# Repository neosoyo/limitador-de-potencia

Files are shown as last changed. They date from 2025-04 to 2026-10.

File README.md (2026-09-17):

# Limitador de Potência
Dispositivo para medição de potência e consumo com controlador de limitador de potência para propulsão elétrica de Aeronaves rádio controladas.

# Configurador

Aplicativo para visualização de daods e ajustes da malha de controle.

# Hardware
Utiliza MCU nrf52 (xiao ble), com os seguintes periféricos:

| Periférico | Descrição |
|---|---|
| INA226 | Leitor de corrente, tensão e potência, R shunt de 50mOhms |
| SK6812mini | Led rgba para indicão de status |
| Saída PWM | com BSS138 para ajuste de nível lógico em 5Vdc |
| Entrada PWM | com BSS138 para ajuste de nível lógico para 3.3Vdc |
| Saída UART | 115200 bps, saída de dados em tempo real do control | 
| BLE | Transmissão de informações me tempo real via BLE |

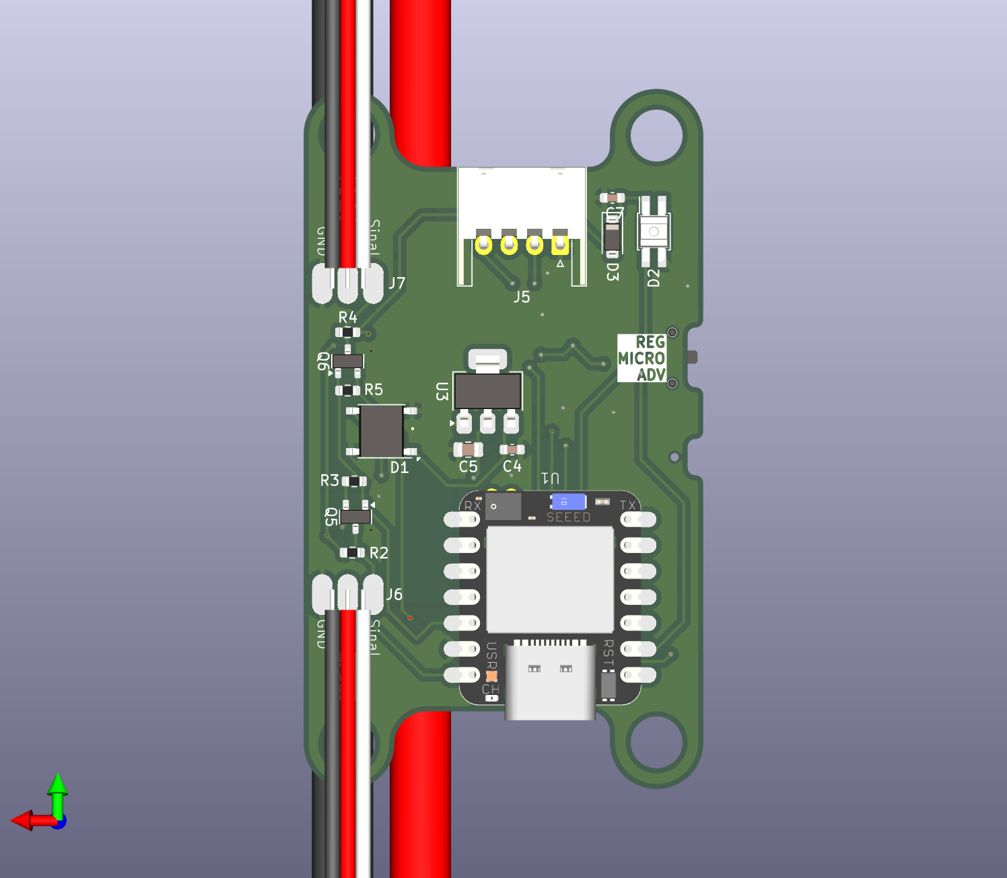
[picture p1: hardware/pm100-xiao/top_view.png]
PM100 Top rev2

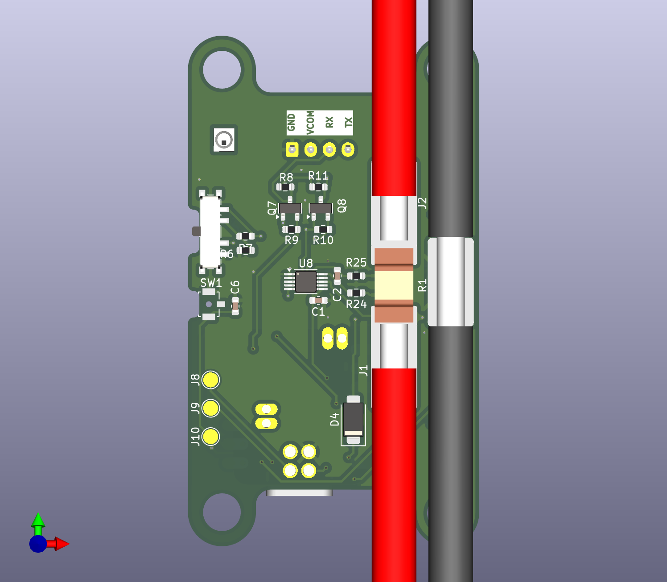
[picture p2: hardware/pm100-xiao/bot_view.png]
PM100 bot rev2


# Firmware

Metas:

* Executar limitação de potência regulando sinal PWM utilizando mensurações do INA226 e uma malha de controle to tipo ADRC.
* Fornecer Potência, Tensão, Corrente, Energia Consumida e sinais PWMs (entrada, controle e saída) pela porta UART.
* Permitir a configuração de número de idenficação e ajuste da malha de controle pela porta USB.
* Através de comunicação bluetooth BLE, transmitir tempo total ligado em segundos, potência máxima, número de identificação e acumulado de energia consumida.
* Suportar bootloader com assinatura de firmware.

# Futuro

Adicionar um monitor de células da bateria: https://www.analog.com/media/en/technical-documentation/data-sheets/ltc6810-1-6810-2.pdf

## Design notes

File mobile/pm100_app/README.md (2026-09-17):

# PM100 Power Limiter — Flutter BLE App

A Flutter + Dart mobile app that connects to the **PM100 Power Limiter** over
Bluetooth Low Energy (BLE), displays live telemetry, and sends a "blink" command
to the device.

- **Stack:** Flutter (Dart), `flutter_blue_plus`
- **Platforms:** Android, iOS
- **Device:** PM100 Power Limiter (Seeed Studio Xiao BLE, Zephyr-based firmware)

---

## Features

- Scan for nearby BLE devices and connect to the PM100.
- Secure pairing via MITM passkey (the device requires encryption on all GATT
  characteristics; the OS shows the numeric PIN prompt automatically).
- Subscribe to `NOTIFY` characteristics for live telemetry updates.
- Read `READ`-only characteristics (Uptime, Team Name, Team Number) on connect
  and via a manual refresh button.
- Send the **White Blink** command (`0x01`) from a dedicated button.
- Decode and scale the raw binary payloads into human-readable values.
- Show **PWM Signals** as three 0–2000 µs progress bars.
- Light / dark theme toggle (initialized from the phone's brightness), using Android's **Material You** dynamic color (via `dynamic_color`), falling back to a seed color elsewhere.

---

## Project structure

```
lib/
  main.dart                          # App entry, theme, HomeScreen (view switch)
  models/
    pm100_spec.dart                  # UUIDs, variable definitions, value decoders
  services/
    pm100_ble_controller.dart        # BLE lifecycle + state (ChangeNotifier)
  screens/
    scan_screen.dart                 # Device discovery & connection UI
    device_screen.dart               # Telemetry list + Blink button

test/
  widget_test.dart                   # Unit tests for value formatting

android/app/src/main/AndroidManifest.xml  # BLE permissions
ios/Runner/Info.plist                      # Bluetooth usage descriptions
```

### Architecture

- `Pm100BleController` is a `ChangeNotifier` that owns the entire BLE
  lifecycle. The UI is stateless and rebuilds through a `ListenableBuilder`.
- `HomeScreen` switches between `ScanScreen` and `DeviceScreen` based on
  `controller.isReady`.

```mermaid
flowchart TD
    A[ScanScreen] -->|tap device| B[connect]
    B --> C[discoverServices]
    C --> D[Subscribe NOTIFY characteristics]
    D --> E[Read READ characteristics]
    E --> F[DeviceScreen - live telemetry]
    F --> G[Blink button writes 0x01]
    F --> H[Refresh re-reads values]
    H --> F
    F -->|disconnect| A
```

---

## BLE service specification

### Service UUID

| Item | UUID |
|---|---|
| **PM100 Service** | `E20A1A00-473B-4444-9F6D-BE083A8BD92D` |

Standard 16-bit SIG characteristics use the Bluetooth Base UUID
`0000XXXX-0000-1000-8000-00805F9B34FB`. Custom characteristics use their full
128-bit UUID.

### Characteristics

| Parameter | GATT name | UUID | Properties | Format | Size |
|---|---|---|---|---|---|
| Voltage | Voltage | `0x2B18` | `NOTIFY`, `READ` | `uint16` mV → `11.80 V` | 2 B |
| Current | Current | `0x2B17` | `NOTIFY`, `READ` | `uint16` mA → `10.20 A` | 2 B |
| Power | Power | `E20A1A08-…` | `NOTIFY`, `READ` | `uint32` mW → `600.0 W` | 4 B |
| Energy | Energy (Total) | `0x2B06` | `NOTIFY`, `READ` | `uint32` J → `450 J` | 4 B |
| Uptime | Time ms | `0x2A2B` | `NOTIFY`, `READ` | `uint32` ms → duration | 4 B |
| PWM Signals | PWM State | `E20A1A03-…` | `NOTIFY`, `READ` | 3× `uint16` µs (`IN`/`OUT`/`CTRL`) | 6 B |
| Control State | Control State | `E20A1A07-…` | `NOTIFY`, `READ` | `uint8` enum | 1 B |
| Team Name | Team Name | `E20A1A04-…` | `READ` | UTF-8, null-terminated (≤ 32 B) | ≤ 32 B |
| Team Number | Team Number | `E20A1A05-…` | `READ` | `uint32` | 4 B |
| **White Blink** | Blink Trigger | `E20A1A06-…` | `WRITE` | 1-byte `0x01` (10 blinks) | 1 B |

> All multi-byte values are **little-endian**. All characteristics require
> **encryption** (`BT_GATT_PERM_READ_ENCRYPT`).

### `ctrl_state` enum

| Value | State |
|---|---|
| `0` | `READY` |
| `1` | `LIMITING_POWER` |
| `2` | `ERROR_NO_INPUT` |
| `3` | `ERROR_NO_BATTERY` |
| `4` | `BLINK` |

Unknown values are shown as `UNKNOWN (n)`.

---

## How the app flow works

1. **Scan** — scans for all BLE devices (unfiltered, because the device name is
   dynamically composed as `team_name_team_number_MAC4`).
2. **Connect** — `connect()` skips the MTU request (`mtu: null`) since payloads
   are small.
3. **Discover** — `discoverServices()` then maps discovered characteristics to
   the spec by UUID.
4. **Subscribe** — enables notifications one characteristic at a time, with a
   short delay and a retry on `GATT_WRITE_REQUEST_BUSY`.
5. **Read** — reads the readable characteristics once for a snapshot.
6. **Live updates** — `NOTIFY` values update the UI as they arrive; the
   refresh button re-reads the `READ`-only values.

---

## Running the app

### Prerequisites

- Flutter (stable, tested on 3.47.x / Dart 3.13).
- An Android or iOS device with Bluetooth.
- The PM100 powered on and within range.

### On a physical device (recommended)

The Android emulator has **no Bluetooth adapter**, so use a physical device for
real BLE testing.

```sh
flutter pub get
flutter devices            # confirm the phone is listed
flutter run -d <device-id>
```

### Over Wi-Fi (Android wireless debugging)

1. On the phone: **Developer options → Wireless debugging → On** (same Wi-Fi as
   the PC).
2. Tap **"Pair device with pairing code"**, then on the PC:

   ```sh
   adb pair <IP:port>      # enter the 6-digit code
   adb connect <IP:port>   # the Wireless-debugging port shown on the phone
   ```

3. Confirm it appears in `flutter devices`, then `flutter run -d <device-id>`.

### Build & install only (no attached runner)

```sh
flutter build apk --debug
flutter install -d <device-id> --debug
adb -s <device-id> shell am start -n com.pm100.pm100_app/.MainActivity
```

---

## Platform configuration

- **Android** — BLE permissions are declared in
  `android/app/src/main/AndroidManifest.xml`:
  `BLUETOOTH_SCAN` / `BLUETOOTH_CONNECT` (Android 12+) plus legacy permissions.
  `flutter_blue_plus` requests them at runtime automatically.
- **iOS** — `NSBluetoothAlwaysUsageDescription` is set in
  `ios/Runner/Info.plist`.

---

## Troubleshooting

### `GATT_WRITE_REQUEST_BUSY` on connect

The Zephyr firmware processes one GATT operation at a time and returns this when
a write arrives while it is still busy. The controller mitigates it by:

- skipping the MTU request (`mtu: null`),
- separating the subscribe and read phases,
- adding delays between operations,
- retrying CCCD writes (3 attempts with backoff).

### App shows "Bluetooth not supported"

This happens on the Android emulator (no BLE hardware). Run on a physical device.

### Pin/pairing prompt

The device uses encrypted MITM pairing. The first read/subscribe triggers the OS
numeric PIN dialog — enter the 6-digit passkey configured on the device.

---

## Testing & validation

```sh
flutter analyze    # static analysis
flutter test       # unit tests for value formatting
```

Both currently pass with no issues.

---

## Notes

- `flutter_blue_plus` requires a license: this project uses `License.nonprofit`
  (personal/nonprofit/educational). For commercial use, switch to
  `License.commercial` (paid) — see the package's LICENSE. It is set in
  `lib/services/pm100_ble_controller.dart`.

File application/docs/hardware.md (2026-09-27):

# Power Limiter (Limitador de Potência) - Project Specifications

This project implements a smart power limiter for RC aircraft electric propulsion using the nRF Connect SDK (NCS) / Zephyr RTOS framework. It runs on a Seeed Studio Xiao BLE (nRF52840) MCU, measuring power consumption via an INA226 sensor, processing two RC PWM inputs (pilot throttle and a limiter bypass switch), and regulating a PWM output signal to the Electronic Speed Controller (ESC) using an Active Disturbance Rejection Control (ADRC) law.

---

## Architecture Overview

The system is designed around **four concurrent threads** to handle hard real-time control, high-frequency telemetry, user feedback, and the high-rate binary data stream efficiently.

```
       +---------------------------------------------------------+
       |                  Thread 1: Control (1kHz)               |
       |  - Read INA226 Power        - Read Input PWM Pulse      |
       |  - Compute ADRC Law         - Safe Min-Limit PWM Out    |
       +-------+--------------------------------+----------------+
               |                                |
               | (Shared State,                 | (1 kHz samples +
               |  10 Hz poll)                   |  controller snapshot)
               v                                v
  +-----------------------------+   +-------------------------------------+
  |     Thread 2: Telemetry     |   |     Thread 4: Binary Stream         |
  |           (10 Hz)           |   |      (4 ms default period)          |
  |  - Format controller state  |   |  - Pack 44 B samples / 84 B meta    |
  |    to CSV, 9 fields         |   |    into framed binary packets       |
  |  - USB CDC ACM port 0       |   |  - USB CDC ACM port 1               |
  +--------------+--------------+   +----------------+--------------------+
                 |                                   |
                 | (Status & Error Flags)            | (binary frames)
                 v                                   v
  +-----------------------------+   +-------------------------------------+
  |    Thread 3: Status LED     |   |  Host: /dev/ttyACM1 (port 1)        |
  |           (4 Hz)            |   |  Desktop application (parser)       |
  +-----------------------------+   +-------------------------------------+
```

---

## 1. Thread Specifications

### Thread 1: Control Loop (1kHz / Period: 1ms)
*   **Purpose:** Perform real-time power limiting to prevent motor/battery overload while respecting the pilot's throttle commands.
*   **Control Logic:**
    1.  Read the active throttle input signal ($PWM_{in}$) in microseconds.
    2.  Read the current bus voltage, current, and power ($P_{meas}$) from the INA226 sensor.
    3.  Compute the ADRC control effort command ($u_{ctrl}$) to drive $P_{meas}$ toward the desired $P_{target}$.
    4.  Apply the output limit:
        $$PWM_{out} = \min(PWM_{in}, u_{ctrl})$$
        This guarantees that the controller only restricts power when exceeding the limit and never exceeds the pilot's requested throttle.
    5.  Update status flags (OK, Limiting, or Error) based on throttle input boundaries and control state.
*   **Scheduling:** Set with high preemptive or cooperative priority to ensure minimal jitter.

### Thread 2: Telemetry & Interface (10Hz / Period: 100ms)
*   Purpose: Format, update, and transmit device diagnostics over the communication interfaces (USB CDC ACM console, BLE, and a dedicated physical UART), and handle the BLE interface.
*   Outputs & Ports:
    1.  **USB CDC ACM Console:** The virtual COM port (`cdc_acm_uart0` / Console) of the Seeed Studio Xiao BLE. The CSV stream on this port is toggleable via the shell (activated with `stream on`).
    2.  **Dedicated Physical UART Output:** A physical UART TX output stream (the "third UART / auxiliary port" at 115200 bps, configured via hardware devicetree pins) that continuously transmits the CSV telemetry.
    3.  **Bluetooth BLE:** Broadcasts/transmits the same telemetry buffer packet at 10Hz.
*   Data Format (CSV):
    ```csv
    <time_ms>,<peak_power_w>,<current_a>,<voltage_v>,<total_consumption_j>,<pwm_input_us>,<pwm_output_us>,<pwm_control_us>,<control_state>
    ```
    Where `<peak_power_w>` is the peak power measured since boot, in Watts, and `<control_state>` is represented as an integer:
    * `0` = **`READY`**
    * `1` = **`LIMITING_POWER`**
    * `2` = **`ERROR_NO_INPUT`**
    * `3` = **`ERROR_NO_BATTERY`**
    * `4` = **`BLINK`**
    * `5` = **`LEARNING`**

    *Example Output:*
    ```csv
    34200,120.5,10.2,11.8,450.2,1500,1420,1420,0
    ```
*   Control Shell Features:
    *   Enable/disable the USB console's CSV stream via shell commands.
    *   Maintain Bluetooth BLE transmission and physical UART streaming at the same 10Hz rate.
*   **Transport note:** the 10 Hz CSV stream above is a *human-readable convenience* output. The high-rate machine-readable telemetry is produced by **Thread 4** on a **second USB CDC ACM port** (see §4); the two paths are fully independent.

### Thread 3: Status & Feedback LED (4Hz / Period: 250ms)
*   **Purpose:** Update the single WS2812 RGB LED to provide clear, real-time diagnostic states to the operator.
*   **State Machine & LED Indicators:**

| State | State Integer Value | Condition | LED Color | Blink Frequency | Blink Period |
|---|---|---|---|---|---|
| **READY** | `0` | System ready and healthy, fallback if other states are false | **Green** (e.g., `#00FF00`) | **1 Hz** | Blinks every 1s (500ms ON, 500ms OFF) |
| **LIMITING_POWER**| `1` | ADRC actively limiting power, $PWM_{out} < PWM_{in}$ | **Blue** (e.g., `#0000FF`) | **4 Hz** | Blinks every 250ms (125ms ON, 125ms OFF) |
| **ERROR_NO_INPUT** | `2` | $PWM_{in} < 900\,\mu\text{s}$ or $PWM_{in} > 2000\,\mu\text{s}$ | **Red** (e.g., `#FF0000`) | **2 Hz** | Blinks every 500ms (250ms ON, 250ms OFF) |
| **ERROR_NO_BATTERY** | `3` | $Voltage < 5.0\,\text{V}$ | **Red** (e.g., `#FF0000`) | **2 Hz** | Blinks every 500ms (250ms ON, 250ms OFF) |
| **BLINK** | `4` | Triggered via CLI or BLE, overrides all other states | **White** (e.g., `#FFFFFF`) | **5 Hz** | Blinks every 200ms (100ms ON, 100ms OFF) for 5 seconds |
| **LEARNING** | `5` | ADRC b0 learning mode active ($b_0 = 0$) | **Orange** (e.g., `#FF7F00`) | **4 Hz** | Blinks every 250ms (125ms ON, 125ms OFF) |
### Thread 4: Binary Telemetry Stream (4ms default period / 250Hz framing)
*   **Purpose:** Ship *every* 1 kHz control-loop sample plus the ADRC internals to a desktop application without disturbing the shell or the control loop.
*   **Inputs:** Lock-free single-producer/single-consumer (SPSC) ring buffer filled by Thread 1.
*   **Behaviour:**
    1.  Thread 1 converts each control tick to a 44-byte fixed-point sample and pushes it into an 8 KiB ring (two small `memcpy`s, no formatting, no allocation).
    2.  Thread 4 wakes every `period_ms` (default 4 ms), drains the ring, and emits one frame of up to 48 samples.
    3.  Frames are handed to the port with a single `uart_fifo_fill()` call, i.e. one call per frame instead of one work-item per byte (which is what the `printf`/console path costs).
    4.  A controller/configuration snapshot (84 bytes, 1 Hz *and* after every parameter change) is interleaved between sample frames so a capture is self-describing.
*   **Scheduling:** `K_PRIO_PREEMPT(8)`, 2048-byte stack. Thread 1 is never blocked by the stream: if the host stalls, the ring simply overflows and the drop is counted.
*   **Details:** see §4.

**Latency/bandwidth trade-off:** `period_ms` sets how many samples share one frame. Total bandwidth stays between ~44 and ~52 kB/s regardless (the header is only 8 bytes), so the knob only trades frame count against latency — 1 ms gives ~1 ms latency at 1000 frames/s, 48 ms gives ~48 ms latency at ~21 frames/s.
---

## 2. Non-Volatile Storage (NVS) & Settings Subsystem Configuration

To ensure parameter persistence across power cycles, all device configuration variables and Bluetooth bonding keys are stored in the internal flash memory using Zephyr's unified **Settings Subsystem** backed by the Non-Volatile Storage (NVS) file system. This prevents double-mounting conflicts on the shared flash partition.

### Configuration Structure

All parameters are packed into a single serializable C struct:

```c
struct __attribute__((packed)) device_config {
    /* ADRC Controller Parameters */
    float dt;              // Controller sampling time step (seconds)
    float wo;              // Observer bandwidth (rad/s)
    float b0;              // Controller input gain scaling factor
    float kp;              // Proportional gain
    float kd;              // Derivative gain
    float target_power;    // Initial/Default Power Target in Watts

    /* Team & Identification Information */
    char team_name[32];    // Team name string (up to 32 bytes, null-terminated)
    uint32_t team_number;  // Unique identifier for the team / controller
    char PIN_code[7];      // 6-character security PIN (+1 byte for null terminator)
};
```

### Operational Rules
*   **Mounting and Storage:** On startup, the Settings Subsystem automatically mounts and manages the flash storage partition (typically `storage_partition`) using NVS. Both application parameters and Bluetooth stack state (bonding keys, CCCDs) share this unified storage.
*   **Loading Configuration:**
    *   The system initializes the settings backend via `settings_subsys_init()` and registers a static handler under the path `"app/device"`.
    *   `settings_load()` is called to retrieve and load the stored `device_config` structure.
    *   If no config is found (first-time boot), a set of sensible default values is written, and the device proceeds with these defaults.
*   **Writing Configuration:** Any update to the ADRC gains, target power, team info, or PIN via the shell triggers an immediate write back to persistent storage using `settings_save_one("app/device", ...)` to ensure durability.

---

## 3. Shell Interface Specifications

The shell interface is accessible over the default USB serial terminal. It supports the following commands:

### Configuration Commands

#### `update_adrc_gains <wo> <b0> <kp> <kd>`
*   **Description:** Updates the active ADRC controller gains and saves them directly to NVS.
*   **Arguments:** Floating-point parameters for $w_o, b_0, K_p, K_d$. The sampling time step is fixed at 1 ms by the 1 kHz control loop.
*   **b0 Learning Mode:** Passing `0` as `<b0>` enables the identification mode. The controller passes the pilot throttle through (with a 1.2× target-power safety cap) while collecting moving averages of power in the 10-50% and 75-100% throttle bands. Three alternating throttle steps (low→high, high→low, low→high) are captured; each step's time constant $\tau_m$ is estimated with a log-linear least-squares fit, and the median of the three estimates is used. The controller then derives and saves $b_0 = \Delta P/(\tau_m^2 \Delta U)$, $w_c = 2/\tau_m$, $K_p = w_c^2$, $K_d = 2 w_c$, and $w_o = 5 w_c$. Inconsistent step estimates restart the learning automatically. The default `b0 = 0` triggers this on first boot.

#### `target <power_watts>`
*   **Description:** Sets the active power target limit.
*   **Arguments:** Floating-point power target in Watts. Saves to NVS immediately.

#### `set_team <number> <name>`
*   **Description:** Configures the team identification parameters.
*   **Arguments:**
    *   `<number>`: Unsigned integer team number.
    *   `<name>`: Character string (up to 31 characters) representing the team name.
*   **Storage:** Saves to NVS immediately.

#### `set_pin <pin_code>`
*   **Description:** Updates the device's 6-digit PIN code.
*   **Arguments:** A 6-character string representing the security PIN.
*   **Storage:** Saves to NVS immediately.

#### `stream <on|off>` | `stream csv <on|off>`
*   **Description:** Activates or deactivates the 10 Hz real-time CSV telemetry streaming on the default console port (port 1). `stream csv <on|off>` is the explicit spelling of the same thing.

#### `stream bin <on|off> [period_ms]`
*   **Description:** Activates or deactivates the binary telemetry stream on the **second CDC ACM port** (port 2, see §4).
*   **Arguments:**
    *   `<on|off>`: enables or disables the stream. Normally open this port **before** enabling, otherwise the first frames are dropped.
    *   `[period_ms]`: optional frame period, `1`–`48`, default `4`. Because the stream is fed by the 1 kHz control loop, this is also the number of samples per frame (4 ms → 4 samples/frame at 250 frames/s).
*   **Behaviour:** Disabling only stops new samples; a frame already in flight is completed so the host never sees a truncated frame. Enabling starts from an empty ring, so the host sees current data, not a stale backlog.

#### `stream status`
*   **Description:** Prints the state of both streams plus the binary stream diagnostics: frame and sample counters (sent/dropped), mid-frame TX stalls and framing errors. Use it to tell "the host is not reading" (drops rising, stalls rising) from "the device is not producing" (counters flat).

#### `readings`
*   Description: Triggers a single print of the current telemetry values in CSV format.

---

## 4. Binary Telemetry Stream (Second USB CDC ACM Port)

### 4.1 Motivation and port topology

The console port must stay interactive, and in this build it is shared with *all* log output (the log backend is the shell backend, `CONFIG_SHELL_LOG_BACKEND=y`), which makes it line-oriented, DTR-gated and unsuitable for binary traffic. Instead of multiplexing binary data into it, the device instantiates a **second CDC ACM interface** and dedicates a port to telemetry.

| Property | Port 1 — console/shell | Port 2 — telemetry |
|---|---|---|
| Devicetree node | `board_cdc_acm_uart` | `stream_cdc_acm_uart` |
| USB interface numbers | 0 (control) + 1 (data) | 2 (control) + 3 (data) |
| Linux | `/dev/ttyACM0` | `/dev/ttyACM1` |
| Windows device instance | `...&MI_00` | `...&MI_02` |
| Carries | shell, `printf`, LOG, 10 Hz CSV | binary frames only |
| Shell available | yes | no |

Both interfaces belong to **one USB device**, therefore they share a single `idVendor`/`idProduct` (`CONFIG_USB_DEVICE_VID=0x2FE3`, `CONFIG_USB_DEVICE_PID=0x0100`) and one serial number; a VID/PID pair cannot be assigned per interface. Distinguish the ports by interface number:

```
# /etc/udev/rules.d/60-pm100.rules
SUBSYSTEM=="tty", ATTRS{idVendor}=="2fe3", ATTRS{idProduct}=="0100", \
  ENV{ID_USB_INTERFACE_NUM}=="00", SYMLINK+="pm100_shell"
SUBSYSTEM=="tty", ATTRS{idVendor}=="2fe3", ATTRS{idProduct}=="0100", \
  ENV{ID_USB_INTERFACE_NUM}=="02", SYMLINK+="pm100_stream"
```

Zephyr's `cdc_interface_config()` rebases the interface numbers per instance at build time, so the device enumerates as a single configuration with two IADs (interfaces 0-1 and 2-3). The device never reads the telemetry port, so the host may open it without asserting DTR. Baud rate is meaningless for both ports: USB CDC stores the host's line coding but no clock is derived from it.

### 4.2 Wire format

Little-endian, packed, no padding. `frame := header payload`.

**Header — 8 bytes**

| Offset | Type | Field | Notes |
|---|---|---|---|
| 0 | `u8` | `magic` | always `0xA5` |
| 1 | `u8` | `version` | currently `0x01` |
| 2 | `u8` | `type` | `1` = samples, `2` = controller snapshot |
| 3 | `u16` | `seq` | frame counter, +1 per frame, wraps at 65536 |
| 5 | `u8` | `count` | items in the payload (samples 1..48, snapshot 1) |
| 6 | `u16` | `len` | payload length in bytes |

**Payload type 1 — `pm100_stream_sample`, 44 bytes per item**

| Offset | Type | Field | Unit / scaling | Meaning |
|---|---|---|---|---|
| 0 | `u32` | `t_ms` | ms | uptime (wraps after ~49.7 days) |
| 4 | `i32` | `e_j` | J | accumulated energy |
| 8 | `i32` | `z1_mw` | mW | LESO $z_1$ — estimated power |
| 12 | `i32` | `z2_mws` | mW/s | LESO $z_2$ — estimated $\dot P$ |
| 16 | `i32` | `z3_mws` | mW/s | LESO $z_3$ — total disturbance |
| 20 | `u16` | `v_cv` | 10 mV (`2550` = 25.50 V) | bus voltage |
| 22 | `i16` | `i_ca` | 10 mA (`1250` = 12.50 A) | current |
| 24 | `i16` | `y_dw` | 0.1 W | measured power — controller input $y$ |
| 26 | `u16` | `pmax_w` | W | peak power since boot |
| 28 | `i16` | `tgt_dw` | 0.1 W | power target — reference $r$ |
| 30 | `u16` | `pwm_in` | µs | pilot throttle input |
| 32 | `u16` | `pwm_out` | µs | applied ESC pulse $\min(PWM_{in}, u)$ |
| 34 | `u16` | `pwm_ctrl` | µs | ADRC effort after clamping |
| 36 | `i16` | `pwm_ctrl_raw` | µs | ADRC effort **before** clamping (wind-up) |
| 38 | `u8` | `state` | enum | `ctrl_state`, same numbering as the CSV |
| 39 | `u8` | `flags` | bitfield | see below |
| 40 | `u8[4]` | `_rsvd` | — | reserved, keeps the item 4-byte aligned |

`flags` bits:

| Bit | Mask | Name | Meaning |
|---|---|---|---|
| 0 | `0x01` | `INPUT_VALID` | throttle pulse inside 900–2000 µs |
| 1 | `0x02` | `BATTERY_VALID` | bus voltage ≥ 5.0 V |
| 2 | `0x04` | `SAFE` | both of the above, so the control law ran |
| 3 | `0x08` | `LEARNING` | b0 identification mode active |
| 4 | `0x10` | `LEARN_POWER_CUT` | learning safety cap tripped |
| 5 | `0x20` | `ADRC_SATURATED` | raw effort was clamped to 1000–2000 µs |
| 6 | `0x40` | `SENSOR_ERROR` | INA226 read failed this tick (v/i forced to 0) |

> `z1_mw`, `z2_mws`, `z3_mws` and `pwm_ctrl_raw` are only meaningful on ticks where the control law actually ran (`SAFE` set and `LEARNING` clear); they hold the previous value otherwise.

**Payload type 2 — `pm100_stream_meta`, 84 bytes** (sent once per second *and* immediately after any parameter change)

| Offset | Type | Field | Unit | Notes |
|---|---|---|---|---|
| 0 | `f32` | `wo` | rad/s | observer bandwidth |
| 4 | `f32` | `b0` | — | controller input gain |
| 8 | `f32` | `kp` | — | proportional gain |
| 12 | `f32` | `kd` | — | derivative gain |
| 16 | `f32` | `l1` | — | $3 w_o$ |
| 20 | `f32` | `l2` | — | $3 w_o^2$ |
| 24 | `f32` | `l3` | — | $w_o^3$ |
| 28 | `f32` | `target_power` | W | active power target |
| 32 | `f32` | `shunt_mohm` | mΩ | configured shunt |
| 36 | `f32` | `dt` | s | control period |
| 40 | `u32` | `uptime_ms` | ms | when the snapshot was taken |
| 44 | `u32` | `team_number` | — | team / controller number |
| 48 | `char[32]` | `team_name` | — | NUL-padded |
| 80 | `u8` | `learning_stage` | enum | `learning_stage` |
| 81 | `u8[3]` | `_rsvd` | — | reserved |

**Reference Python decoder** (the sizes are enforced at compile time by the `BUILD_ASSERT`s in `src/stream.h` / `src/stream.c`):

```python
import struct

HDR    = struct.Struct("<BBBHBH")               # 8 B
SAMPLE = struct.Struct("<IiiiihhHhHHHhBB4x")    # 44 B
META   = struct.Struct("<10fII32sB3x")          # 84 B

TYPE_SAMPLES, TYPE_META = 1, 2
MAGIC, VERSION = 0xA5, 0x01

def parse(fh):
    """Yield (type, tuple) per frame; resynchronises on garbage."""
    buf = bytearray()
    while True:
        chunk = fh.read(4096)
        if not chunk:
            return
        buf += chunk
        while True:
            i = buf.find(MAGIC)
            if i < 0:
                del buf[:max(0, len(buf) - 1)]   # keep a possibly split magic
                break
            del buf[:i]
            if len(buf) < HDR.size:
                break
            magic, ver, ftype, seq, count, plen = HDR.unpack_from(buf)
            item = {TYPE_SAMPLES: SAMPLE, TYPE_META: META}.get(ftype)
            if ver != VERSION or item is None or plen != count * item.size:
                del buf[:1]                       # false magic, resync
                continue
            if len(buf) < HDR.size + plen:
                break
            payload = buf[HDR.size:HDR.size + plen]
            for n in range(count):
                yield ftype, item.unpack_from(payload, n * item.size)
            del buf[:HDR.size + plen]
```

### 4.3 Host parser rules

1. Scan for `0xA5`; accept a frame only if `version == 1` and `len == count × item_size` — that is enough to resynchronise after any noise.
2. A jump in `seq` means whole **frames** were lost (e.g. the host stopped reading).
3. A jump in `t_ms` means individual **samples** were dropped on-device (ring overflow).
4. No per-frame CRC is needed: USB bulk already carries a link-layer CRC with retransmission. `magic` + `len` + `seq` cover framing and loss detection.

### 4.4 Rates, latency and bandwidth

| Metric | Value |
|---|---|
| Sample rate | 1000 samples/s (every 1 kHz control tick) |
| Default period | 4 ms → 4 samples/frame, 250 frames/s |
| Frame size (`period_ms = 4`) | 8 + 4 × 44 = 184 B |
| Sample stream | ≈46 kB/s (≈368 kbit/s, ≈3 % of Full-Speed USB) |
| Snapshot stream | 92 B/s (1 Hz) |
| Latency | ≈ `period_ms` + USB transfer + host read |
| Ring slack | 8 KiB ≈ 186 samples ≈ 186 ms of host stall absorbed |

Total bandwidth stays between ≈44 and ≈52 kB/s for any `period_ms` (the 8-byte header is negligible), so the knob only trades **latency against frame count**: `period_ms = 1` gives ≈1 ms latency at 1000 frames/s, `period_ms = 48` gives ≈48 ms at ≈21 frames/s.

For comparison, the 10 Hz CSV on the console port is ≈0.7 kB/s; streaming that same CSV at 1 kHz would be ≈70 kB/s *and* would be limited by `%f` software-double formatting rather than by the wire.

### 4.5 Build configuration

`prj.conf`:
```
CONFIG_USB_CDC_ACM_RINGBUF_SIZE=4096
```
The CDC ACM ring buffer size is global, i.e. it applies to TX **and** RX of **both** instances (16 kB of RAM). It is much larger than the largest frame (2120 B) so that a whole frame is normally accepted by a single `uart_fifo_fill()` call.

`boards/xiao_ble_nrf52840.overlay`:
```dts
&zephyr_udc0 {
	stream_cdc_acm_uart: stream_cdc_acm_uart {
		compatible = "zephyr,cdc-acm-uart";
	};
};
```

Endpoint budget: each CDC ACM instance takes 2 IN + 1 OUT → 4 IN + 2 OUT of the 7 IN / 7 OUT the nRF52840 USBD exposes (EP0 bidir aside).

### 4.6 Implementation map

| File | Role |
|---|---|
| `src/stream.h` | Wire format definition and public API — the reference for the desktop parser |
| `src/stream.c` | 8 KiB SPSC ring, record framing, frame assembly, `uart_fifo_fill()` TX, Thread 4 |
| `src/control.c` | Per-tick sample production, controller snapshot, `g_adrc.u_raw` |
| `src/main.c` | `stream_init()` call and shell commands |
| `boards/xiao_ble_nrf52840.overlay` | Second `zephyr,cdc-acm-uart` node |
| `prj.conf` | CDC ACM ring buffer size |
| `CMakeLists.txt` | Adds `src/stream.c` to the build |

### 4.7 Error handling

| Condition | Behaviour |
|---|---|
| Second port missing from the devicetree | `stream_init()` returns `-ENODEV`, stream stays disabled, everything else works |
| Host not reading the port | Frames are dropped (counted) instead of written partially, so the host never sees a truncated frame; the ring then overflows and samples are dropped (counted) |
| USB back-pressure mid-frame | The frame is completed before anything else is written, so frames stay frame-aligned |
| Ring misuse / torn record | Detected by the record length check, ring is reset by its owner, `corrupt_records` is bumped |

Diagnostics are exposed with `stream status` (see §3).

---

## 5. Bluetooth BLE Service Specification

To optimize bandwidth and power consumption, the device exposes telemetry parameters using standard Bluetooth SIG 16-bit characteristics and compact, scaled binary integers instead of ASCII CSV strings. Custom metadata and raw signals employ dedicated 128-bit characteristics.

### Custom GATT Service

The PM100 Power Limiter GATT Service is defined by the following custom 128-bit Service UUID:
*   **PM100 Service UUID:** `E20A1A00-473B-4444-9F6D-BE083A8BD92D`

### BLE Link Encryption, Bonding & PIN-Passkey Security

For operator privacy and security, all telemetry characteristics require **Encrypted Link Pairing with Man-in-the-Middle (MITM) protection** and **Persistent Bonding**.

*   **Passkey Pairing:** The 6-digit PIN code configured in the storage `PIN_code` structure acts as the Bluetooth pairing password (Passkey).
*   **Encrypted Attributes:** All GATT characteristics are guarded with `BT_GATT_PERM_READ_ENCRYPT` permissions. If a client attempts to read or subscribe to telemetry without pairing first, the BLE stack automatically halts the request, triggers the numeric passcode entry on the client's screen, and encrypts the communication link.
*   **Persistent Bonding:** Pairing is upgraded to a permanent **Bond**. Pairing keys (bonding keys) and client configuration descriptor (CCCD) subscriptions are saved persistently to flash via the Settings Subsystem. When a previously paired client reconnects, the connection is encrypted automatically without prompting the user to enter the passkey again.
*   **Bond Capacity and Rotation:** To protect resource consumption in flash, the system maintains up to 5 paired devices. If the bond table is full and a new device attempts to bond, the Bluetooth stack automatically deletes and replaces the oldest bond keys (Least Recently Used) to prevent pairing failures.

### Dynamic Device Name Composition

The BLE device name is compiled dynamically at runtime during startup using the following pattern:
$$\text{Device Name} = \text{team\_name}\_\text{team\_number}\_\text{MAC\_last\_4}$$
*Example Compiled Name:* `TeamFalcon_1234_F1A2`

*   `team_name`: String loaded from NVS.
*   `team_number`: Unsigned integer loaded from NVS.
*   `MAC_last_4`: The last 4 hexadecimal characters of the Bluetooth MAC address of the Seeed Studio Xiao BLE.

### Telemetry Characteristics & Standard UUID Mapping

| Parameter | Standard GATT Name | UUID (16-bit or 128-bit) | Properties | Binary Format & Scaling | Bandwidth Size |
|---|---|---|---|---|---|
| **Voltage** | Voltage | `0x2B18` (16-bit) | `NOTIFY`, `READ` | `uint16_t` in Millivolts (mV) (e.g. $11.8\text{V} \rightarrow 11800$) *(Requires Encryption)* | 2 Bytes |
| **Current** | Current | `0x2B17` (16-bit) | `NOTIFY`, `READ` | `uint16_t` in Milliamperes (mA) (e.g. $10.2\text{A} \rightarrow 10200$) *(Requires Encryption)* | 2 Bytes |
| **Energy** | Energy (Total Cons.) | `0x2B06` (16-bit) | `NOTIFY`, `READ` | `uint32_t` in Joules (J) (e.g. $450.2\text{J} \rightarrow 450$) *(Requires Encryption)* | 4 Bytes |
| **Uptime** | Time ms | `0x2A2B` (16-bit) | `READ` | `uint32_t` in milliseconds (ms) from startup *(Requires Encryption)* | 4 Bytes |
| **PWM Signals** | PWM Signals State | `E20A1A03-473B-4444-9F6D-BE083A8BD92D` | `NOTIFY`, `READ` | Array of 3x `uint16_t` representing $PWM_{in}$, $PWM_{out}$, $PWM_{ctrl}$ in microseconds *(Requires Encryption)* | 6 Bytes |
| **Team Name** | Team Name | `E20A1A04-473B-4444-9F6D-BE083A8BD92D` | `READ` | UTF-8 encoded string (up to 32 bytes, null-terminated) *(Requires Encryption)* | Up to 32 Bytes |
| **Team Number** | Team Number | `E20A1A05-473B-4444-9F6D-BE083A8BD92D` | `READ` | `uint32_t` representing the unique team index *(Requires Encryption)* | 4 Bytes |
| **White Blink Cmd**| White Blink Trigger | `E20A1A06-473B-4444-9F6D-BE083A8BD92D` | `WRITE` | 1-byte Boolean (`0x01` to trigger 10x white blinks) *(Requires Encryption)* | 1 Byte |
| **Peak Power** | Peak Power (since boot) | `E20A1A08-473B-4444-9F6D-BE083A8BD92D` | `NOTIFY`, `READ` | `uint32_t` in Milliwatts (mW) representing the peak power measured since boot (e.g. $600.0\text{W} \rightarrow 600000$) *(Requires Encryption)* | 4 Bytes |
| **Control State** | Control State | `E20A1A07-473B-4444-9F6D-BE083A8BD92D` | `NOTIFY`, `READ` | `uint8_t` representing the `ctrl_state` enum value *(Requires Encryption)* | 1 Byte |

### Bandwidth Comparison & Optimization

*   **ASCII CSV Telemetry Stream:** ~55 bytes per packet $\times$ 10Hz = **550 bytes/second** (4400 bps).
*   **Split Binary Integer Stream:** 19 bytes total per packet $\times$ 10Hz = **190 bytes/second** (1520 bps).
*   **Net Bandwidth Saving:** **~65% reduction** in radio airtime, lowering power consumption and eliminating frame fragmentation. Static identification data (Team Name and Number) are read once on connection, avoiding unnecessary periodic bandwidth consumption.

---

## 6. Implementation Guidelines (AI Instructions)

1.  **Scope Restrictions:**
    *   Only modify files inside the `/src` folder.
    *   **Do not** make any modifications to files within `/src/lipe` or outside of `/src` (with the exception of verifying headers/interfaces).
    *   **Documented exception — binary telemetry stream (§4):** adding the second USB CDC ACM port necessarily touches build/configuration files, namely `boards/xiao_ble_nrf52840.overlay` (the new `zephyr,cdc-acm-uart` node), `prj.conf` (`CONFIG_USB_CDC_ACM_RINGBUF_SIZE`) and `CMakeLists.txt` (adding `src/stream.c`). Keep such edits to the minimum the feature requires and do not extend them to unrelated settings.
2.  **Documentation Standards:**
    *   Provide brief, clear documentation headers for all newly created functions.
    *   Follow the naming conventions already present in the codebase.
3.  **Concurrency & Safety:**
    *   Utilize Zephyr thread primitives (e.g., `K_THREAD_DEFINE`) to schedule the four threads.
    *   Implement basic thread safety (e.g., mutexes, atomic flags, or volatile variables) for variables shared across Thread 1, Thread 2, Thread 3, and Thread 4.
    *   Respect the producer/consumer contract of the telemetry stream: `stream_push_sample()` and `stream_push_meta()` may only be called from Thread 1 (the sole producer), the sample ring is a lock-free SPSC structure, and `ring_buf_reset()` may only run on the producer side (gated by `g_stream_reset_req`).

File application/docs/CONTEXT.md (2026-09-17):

# PM100 Configurator - Desktop Architecture & Context

This document serves as the high-level system architecture, design blueprint, and development guide for the **PM100 Power Limiter Configurator App**. It integrates the hardware specs (`hardware.md`), the core project goals (`projeto.md`), and the user interface requirements (`mockup.png`).

---

## 1. System Architecture Overview

The PM100 Configurator is a **desktop** application written in **Rust** using the **Dioxus** framework. It acts as the user-facing interface for the PM100 smart power limiter hardware, communicating over a USB CDC ACM virtual serial port:

```
                 +-----------------------------------+
                 |        Dioxus App UI Core         |
                 |  - State: Dioxus Signals          |
                 |  - Desktop View                   |
                 +-----------------+-----------------+
                                   |
                   Polymorphic connection interface
                   (via Hardware Abstraction Trait)
                                   |
                                   v
                 +-----------------------------------+
                 |   USB CDC ACM Serial Port         |
                 |   Crate: serialport               |
                 +-----------------+-----------------+
                                   |
                            USB CDC ACM (10Hz)
                                   |
                                   v
                 +-----------------------------------+
                 |    PM100 MCU (nRF52840)           |
                 |  - Zephyr RTOS Firmware           |
                 |  - INA226 Power Sensor            |
                 +-----------------------------------+
```

---

## 2. Hardware Interface & Communication Protocol

### USB CDC ACM Console

The app connects to the PM100 via its Virtual COM Port (`cdc_acm_uart0`).

*   **Initialization:** The app opens the serial port (at 115200 bps) and must send the shell command:
    ```bash
    stream on\n
    ```
    This triggers the PM100 firmware to continuously output telemetry CSV lines at 10Hz.
*   **Data Parsing:** Telemetry is received as a UTF-8 CSV string:
    ```csv
    <time_ms>,<power_w>,<current_a>,<voltage_v>,<total_consumption_j>,<pwm_input_us>,<pwm_output_us>,<pwm_control_us>
    ```
*   **Config Writing:** To write settings, the app sends CLI commands followed by a newline:
    *   **ADRC Gains:** `update_adrc_gains <dt> <wo> <b0> <kp> <kd>` (e.g. `update_adrc_gains 0.002 100 1.0 1.2 0.1\n`)
    *   **Power Target:** `target <power_watts>`
    *   **Team Configuration:** `set_team <number> <name>`
    *   **6-Digit PIN Code:** `set_pin <pin_code>`

---

## 3. Best-Practice Rust Design

To share code across connection implementations, we use a **Polymorphic Connection Pattern** (using a Rust `Trait`). This separates the UI layout from the hardware communication library.

### A. The `DeviceConnection` Trait
Define this trait in a shared module (`src/connection/mod.rs`):

```rust
use async_trait::async_trait;
use tokio::sync::mpsc::Receiver;

#[derive(Debug, Clone, Default)]
pub struct TelemetryData {
    pub time_ms: u32,
    pub power_w: f32,
    pub current_a: f32,
    pub voltage_v: f32,
    pub total_consumption_j: f32,
    pub pwm_input_us: u16,
    pub pwm_output_us: u16,
    pub pwm_control_us: u16,
}

#[derive(Debug, Clone)]
pub struct DeviceConfigData {
    pub dt: f32,
    pub wo: f32,
    pub b0: f32,
    pub kp: f32,
    pub kd: f32,
    pub target_power: f32,
    pub team_name: String,
    pub team_number: u32,
    pub pin_code: String,
}

#[async_trait]
pub trait DeviceConnection: Send + Sync {
    // Connection Lifecycle
    async fn connect(&self) -> Result<(), String>;
    async fn disconnect(&self) -> Result<(), String>;
    async fn is_connected(&self) -> bool;

    // Telemetry Interface
    // Returns a receiver channel for real-time 10Hz updates
    async fn subscribe_telemetry(&self) -> Result<Receiver<TelemetryData>, String>;

    // Configuration / Writes
    async fn update_adrc_gains(&self, dt: f32, wo: f32, b0: f32, kp: f32, kd: f32) -> Result<(), String>;
    async fn update_target_power(&self, target_watts: f32) -> Result<(), String>;
    async fn update_team_config(&self, team_number: u32, team_name: &str) -> Result<(), String>;
    async fn update_pin_code(&self, pin_code: &str) -> Result<(), String>;
    async fn trigger_blink(&self) -> Result<(), String>;
}
```

### B. Concrete Implementations

1.  **`UsbConnection` (Desktop):**
    *   Uses the `serialport` crate to open the virtual COM port.
    *   Spawns a background thread that reads the serial buffer line-by-line, parses incoming CSV strings, and pushes parsed `TelemetryData` to the telemetry channel.
    *   Writes commands as formatted CLI text (e.g. `format!("target {}\n", target_watts)`).
2.  **`MockConnection` (Simulation / Offline Development):**
    *   *Extremely critical for rapid prototyping.*
    *   Does not talk to hardware; instead, it runs an asynchronous timer loop simulating random/smooth walk voltages, currents, and control parameters (e.g., simulating motor revving and power drops).
    *   Allows 100% of UI design, layout, forms, animations, and stream plotting to be built and verified offline without physical MCU units.

---

## 4. Concurrency & State Management in Dioxus

To maintain an ultra-smooth **60 FPS interface** while dealing with rapid 10Hz serial telemetry, we must **never** perform hardware polling or blocking operations on Dioxus's UI rendering thread.

### Concurrency Pipeline Blueprint
```
+-------------------------------------------------------------+
|                     BACKGROUND TASK                         |
|  - Continuous USB CDC Serial Reader                         |
|  - Receives Raw Packets -> Maps to TelemetryData struct     |
+------------------------------+------------------------------+
                               |
                   Rust async channel (mpsc)
                               |
                               v
+-------------------------------------------------------------+
|                   DIOXUS COROUTINE (Task)                   |
|  - Spawns async loop using `spawn()` in Dioxus              |
|  - Awaits channel `.recv().await`                           |
|  - Updates global UI signals atomically                     |
+------------------------------+------------------------------+
                               |
                     Dioxus Signal Writes
                               |
                               v
+-------------------------------------------------------------+
|                        RENDER TREE                          |
|  - Re-renders ONLY the telemetry components (fast path)     |
|  - Pushes metrics to dynamic Stream Data Plot               |
+-------------------------------------------------------------+
```

### Reactive UI State Design
Use **Dioxus Signals** (`use_signal`) to hold active state:
*   `active_telemetry`: Stores the latest `TelemetryData` containing current power, current, voltage, and uptime.
*   `connection_status`: Represents enum states `Disconnected`, `Connecting`, or `Connected`.
*   `telemetry_history`: A double-ended queue (`VecDeque`) storing the last $N$ telemetry data points (typically last 100-200 frames) used to feed the stream chart dynamically.

---

## 5. UI Layout & Component Organization

### Desktop View
*   **Stream Data Plot (Left Column - 60% Width):** Uses an interactive, high-performance SVG viewport or specialized UI chart rendering the history queue (`telemetry_history`). Displays curves for the PWM signals, real-time power, max power, and energy in real-time.
*   **Live Metrics Panel (Center Column - 20% Width):** Vertically stacked typography presenting Live Power ($W$), Max Power ($W$), Voltage ($V$), Current ($A$), and Joules ($J$).
*   **Analog Levels (Right Column - 20% Width):** Three dynamic, colored progress bars representing raw input control levels:
    *   `IN`: Input throttle signal ($PWM_{in}$)
    *   `CTRL`: Controller calculated limits ($PWM_{ctrl}$)
    *   `OUT`: Active output throttle signal sent to ESC ($PWM_{out}$)
*   **Bottom Config Row:** Form inputs for ADRC coefficients (4 active parameters like $w_o, b_0, K_p, K_d$) and Team Data (Number, Name), alongside the security PIN change form.

---

## 6. Prototyping Checklist & Phase Map

### Phase 1: Shared Core & Abstraction
- [ ] Create `src/connection/mod.rs` defining `TelemetryData`, `DeviceConfigData` and `DeviceConnection` trait.
- [ ] Implement `MockConnection` with realistic sensor emulation (sinusoidal power signals, tracking responses to simulate ADRC action).

### Phase 2: Dioxus UI & Interactive Prototyping
- [ ] Create core UI shell with responsiveness built using standard CSS flex/grid structures.
- [ ] Implement custom Dioxus component for **Live Metrics** (optimized text updates).
- [ ] Build **Analog Levels** (vertical/horizontal CSS progress indicators).
- [ ] Design **Stream Data Plot** using standard Dioxus SVG elements (`<svg>` viewport drawing `<polyline>` or `<path>` paths mapped from `telemetry_history`).
- [ ] Build the forms (ADRC parameter sliders/inputs, Team setup) and wire them to the active Connection implementation.

### Phase 3: Desktop Native & Serial Communication
- [ ] Implement `UsbConnection` using `serialport` crate.
- [ ] Set up the background reader thread to monitor serial buffers and parse incoming CLI lines.
- [ ] Validate connection lifecycle: auto-discover Xiao BLE virtual COM ports by VID/PID, send `stream on`, and handle reconnections.

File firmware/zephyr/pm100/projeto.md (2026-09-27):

# Power Limiter (Limitador de Potência) - Project Specifications

This project implements a smart power limiter for RC aircraft electric propulsion using the nRF Connect SDK (NCS) / Zephyr RTOS framework. It runs on a Seeed Studio Xiao BLE (nRF52840) MCU, measuring power consumption via an INA226 sensor, processing two RC PWM inputs (pilot throttle and a limiter bypass switch), and regulating a PWM output signal to the Electronic Speed Controller (ESC) using an Active Disturbance Rejection Control (ADRC) law.

---

## Architecture Overview

The system is designed around **four concurrent threads** to handle hard real-time control, high-frequency telemetry, user feedback, and the high-rate binary data stream efficiently.

```
       +---------------------------------------------------------+
       |                  Thread 1: Control (1kHz)               |
       |  - Read INA226 Power        - Read Input PWM Pulse      |
       |  - Compute ADRC Law         - Safe Min-Limit PWM Out    |
       +-------+--------------------------------+----------------+
               |                                |
               | (Shared State,                 | (1 kHz samples +
               |  10 Hz poll)                   |  controller snapshot)
               v                                v
  +-----------------------------+   +-------------------------------------+
  |     Thread 2: Telemetry     |   |     Thread 4: Binary Stream         |
  |           (10 Hz)           |   |      (4 ms default period)          |
  |  - Format controller state  |   |  - Pack 44 B samples / 84 B meta    |
  |    to CSV, 10 fields        |   |    into framed binary packets       |
  |  - USB CDC ACM port 0       |   |  - USB CDC ACM port 1               |
  +--------------+--------------+   +----------------+--------------------+
                 |                                   |
                 | (Status & Error Flags)            | (binary frames)
                 v                                   v
  +-----------------------------+   +-------------------------------------+
  |    Thread 3: Status LED     |   |  Host: /dev/ttyACM1 (port 1)        |
  |           (4 Hz)            |   |  Desktop application (parser)       |
  +-----------------------------+   +-------------------------------------+
```

---

## 1. Thread Specifications

### Thread 1: Control Loop (1kHz / Period: 1ms)
*   **Purpose:** Perform real-time power limiting to prevent motor/battery overload while respecting the pilot's throttle commands.
*   **Control Logic:**
    1.  Read the active throttle input signal ($PWM_{in}$) in microseconds (P0.28 / XIAO D2).
    2.  Read the limiter bypass switch input signal ($PWM_{bypass}$) in microseconds (P0.29 / XIAO D3).
    3.  Read the current bus voltage, current, and power ($P_{meas}$) from the INA226 sensor.
    4.  Compute the ADRC control effort command ($u_{ctrl}$) to drive $P_{meas}$ toward the desired $P_{target}$, using the **first-order** plant model $\dot P = b_0 u + f$ with a second-order LESO ($z_1 \approx P$, $z_2 \approx f$) — see §3.
    5.  Apply the output limit:
        $$PWM_{out} = \min(PWM_{in}, u_{ctrl})$$
        This guarantees that the controller only restricts power when exceeding the limit and never exceeds the pilot's requested throttle. Two exceptions exist:
        *   **Bypass switch:** when $PWM_{bypass}$ is inside the valid 850–2100 µs window and $\ge 1500$ µs, the controller is bypassed: $u_{ctrl}$ is forced to $PWM_{in}$, so the ESC follows the pilot throttle directly (the limiter is off). Below 1500 µs the controller runs normally.
        *   **Automatic identification** (`pm100 ident run`, see §3): takes ownership of the ESC output for ~4 s and commands its own staircase — deliberately above the pilot's idle stick. That mode still respects the 1000–2000 µs actuator limits, the 400 W power cap and the 20 s timeout, and any stick movement or unsafe condition aborts it on the same tick.
        Safety checks always win: an invalid throttle input or a low battery forces the safe-stop pulse (1000 µs) regardless of the bypass switch.
    6.  Feed the pulse that was actually applied back into the observer (`adrc_set_applied()`), so the LESO integrates the real actuator input rather than a command that the pilot's PWM or the pulse limits may have cut.
    7.  Update status flags (OK, Limiting, Error, or Bypass) based on throttle input boundaries, the bypass switch and the control state. An identification run reports the **LEARNING** state so the LED and the console show an autonomous motor run; an engaged bypass switch reports the **BYPASS** state.
*   **Bypass transitions:** while bypassed the LESO is not advanced, and re-engaging the controller resets the observer so it does not kick from stale states. Engaging the bypass aborts a running identification and restarts an active b0-learning run.
*   **Feedforward:** the control law is $u = u_{ff} + \frac{k_p (r - z_1) - z_2}{b_0}$, where $u_{ff}$ comes from the inverse identification map (0 = pure feedback until `pm100 ident run` has been executed successfully). See §3.
*   **Scheduling:** Set with high preemptive or cooperative priority to ensure minimal jitter.

### Thread 2: Telemetry & Interface (10Hz / Period: 100ms)
*   Purpose: Format, update, and transmit device diagnostics over the communication interfaces (USB CDC ACM console, BLE, and a dedicated physical UART), and handle the BLE interface.
*   Outputs & Ports:
    1.  **USB CDC ACM Console:** The virtual COM port (`cdc_acm_uart0` / Console) of the Seeed Studio Xiao BLE. The CSV stream on this port is toggleable via the shell (activated with `stream on`).
    2.  **Dedicated Physical UART Output:** A physical UART TX output stream (the "third UART / auxiliary port" at 115200 bps, configured via hardware devicetree pins) that continuously transmits the CSV telemetry.
    3.  **Bluetooth BLE:** Broadcasts/transmits the same telemetry buffer packet at 10Hz.
*   Data Format (CSV):
    ```csv
    <time_ms>,<peak_power_w>,<current_a>,<voltage_v>,<total_consumption_j>,<pwm_input_us>,<pwm_bypass_us>,<pwm_output_us>,<pwm_control_us>,<control_state>
    ```
    Where `<peak_power_w>` is the peak power measured since boot, in Watts, `<pwm_bypass_us>` is the limiter bypass switch input pulse in microseconds, and `<control_state>` is represented as an integer:
    * `0` = **`READY`**
    * `1` = **`LIMITING_POWER`**
    * `2` = **`ERROR_NO_INPUT`**
    * `3` = **`ERROR_NO_BATTERY`**
    * `4` = **`BLINK`**
    * `5` = **`LEARNING`**
    * `6` = **`BYPASS`**

    *Example Output:* (bypass switch at 1100 µs → controller active, state `READY`)
    ```csv
    34200,120.5,10.2,11.8,450.2,1500,1100,1420,1420,0
    ```
*   Control Shell Features:
    *   Enable/disable the USB console's CSV stream via shell commands.
    *   Maintain Bluetooth BLE transmission and physical UART streaming at the same 10Hz rate.
*   **Transport note:** the 10 Hz CSV stream above is a *human-readable convenience* output. The high-rate machine-readable telemetry is produced by **Thread 4** on a **second USB CDC ACM port** (see §4); the two paths are fully independent.

### Thread 3: Status & Feedback LED (4Hz / Period: 250ms)
*   **Purpose:** Update the single WS2812 RGB LED to provide clear, real-time diagnostic states to the operator.
*   **State Machine & LED Indicators:**

| State | State Integer Value | Condition | LED Color | Blink Frequency | Blink Period |
|---|---|---|---|---|---|
| **READY** | `0` | System ready and healthy, fallback if other states are false | **Green** (e.g., `#00FF00`) | **1 Hz** | Blinks every 1s (500ms ON, 500ms OFF) |
| **LIMITING_POWER**| `1` | ADRC actively limiting power, $PWM_{out} < PWM_{in}$ | **Blue** (e.g., `#0000FF`) | **4 Hz** | Blinks every 250ms (125ms ON, 125ms OFF) |
| **ERROR_NO_INPUT** | `2` | $PWM_{in} < 850\,\mu\text{s}$ or $PWM_{in} > 2100\,\mu\text{s}$ | **Red** (e.g. `#FF0000`) | **2 Hz** | Blinks every 500ms (250ms ON, 250ms OFF) |
| **ERROR_NO_BATTERY** | `3` | $Voltage < 5.0\,\text{V}$ | **Red** (e.g., `#FF0000`) | **2 Hz** | Blinks every 500ms (250ms ON, 250ms OFF) |
| **BLINK** | `4` | Triggered via CLI or BLE, overrides all other states | **White** (e.g., `#FFFFFF`) | **5 Hz** | Blinks every 200ms (100ms ON, 100ms OFF) for 5 seconds |
| **LEARNING** | `5` | ADRC b0 learning mode active ($b_0 = 0$) | **Orange** (e.g., `#FF7F00`) | **4 Hz** | Blinks every 250ms (125ms ON, 125ms OFF) |
| **BYPASS** | `6` | Bypass switch PWM $\ge 1500\,\mu\text{s}$ (limiter off, throttle passes straight through) | **Purple** (e.g., `#800080`) | **2 Hz** | Blinks every 500ms (250ms ON, 250ms OFF) |
### Thread 4: Binary Telemetry Stream (4ms default period / 250Hz framing)
*   **Purpose:** Ship *every* 1 kHz control-loop sample plus the ADRC internals to a desktop application without disturbing the shell or the control loop.
*   **Inputs:** Lock-free single-producer/single-consumer (SPSC) ring buffer filled by Thread 1.
*   **Behaviour:**
    1.  Thread 1 converts each control tick to a 44-byte fixed-point sample and pushes it into an 8 KiB ring (two small `memcpy`s, no formatting, no allocation).
    2.  Thread 4 wakes every `period_ms` (default 4 ms), drains the ring, and emits one frame of up to 48 samples.
    3.  Frames are handed to the port with a single `uart_fifo_fill()` call, i.e. one call per frame instead of one work-item per byte (which is what the `printf`/console path costs).
    4.  A controller/configuration snapshot (84 bytes, 1 Hz *and* after every parameter change) is interleaved between sample frames so a capture is self-describing.
    5.  While `pm100 ident run` holds a capture window open, the raw samples are also emitted as 12-byte type-3 records (2 x 48 = 96 frames for the whole staircase), so the identification can be re-fitted and audited offline from the same capture.
*   **Scheduling:** `K_PRIO_PREEMPT(8)`, 2048-byte stack. Thread 1 is never blocked by the stream: if the host stalls, the ring simply overflows and the drop is counted.
*   **Details:** see §4.

**Latency/bandwidth trade-off:** `period_ms` sets how many samples share one frame. Total bandwidth stays between ~44 and ~52 kB/s regardless (the header is only 8 bytes), so the knob only trades frame count against latency — 1 ms gives ~1 ms latency at 1000 frames/s, 48 ms gives ~48 ms latency at ~21 frames/s.
---

## 2. Non-Volatile Storage (NVS) & Settings Subsystem Configuration

To ensure parameter persistence across power cycles, all device configuration variables and Bluetooth bonding keys are stored in the internal flash memory using Zephyr's unified **Settings Subsystem** backed by the Non-Volatile Storage (NVS) file system. This prevents double-mounting conflicts on the shared flash partition.

### Configuration Structure

All parameters are packed into a single serializable C struct:

```c
struct __attribute__((packed)) device_config {
    /* ADRC Controller Parameters */
    float dt;              // Controller sampling time step (seconds)
    float wo;              // Observer bandwidth (rad/s)
    float b0;              // Controller input gain scaling factor
    float kp;              // Proportional gain
    float kd;              // Derivative gain
    float target_power;    // Initial/Default Power Target in Watts

    /* Team & Identification Information */
    char team_name[32];    // Team name string (up to 32 bytes, null-terminated)
    uint32_t team_number;  // Unique identifier for the team / controller
    char PIN_code[7];      // 6-character security PIN (+1 byte for null terminator)
};
```

### Operational Rules
*   **Mounting and Storage:** On startup, the Settings Subsystem automatically mounts and manages the flash storage partition (typically `storage_partition`) using NVS. Both application parameters and Bluetooth stack state (bonding keys, CCCDs) share this unified storage.
*   **Loading Configuration:**
    *   The system initializes the settings backend via `settings_subsys_init()` and registers a static handler under the path `"app/device"`.
    *   `settings_load()` is called to retrieve and load the stored `device_config` structure.
    *   If no config is found (first-time boot), a set of sensible default values is written, and the device proceeds with these defaults.
*   **Writing Configuration:** Any update to the ADRC gains, target power, team info, or PIN via the shell triggers an immediate write back to persistent storage using `settings_save_one("app/device", ...)` to ensure durability.

---

## 3. Shell Interface Specifications

The shell interface is accessible over the default USB serial terminal. It supports the following commands:

### Configuration Commands

#### `update_adrc_gains <wo> <b0> <kp> <kd>`
*   **Description:** Updates the active ADRC controller gains and saves them directly to NVS.
*   **Plant model (first order):** the controller assumes
    $$\dot P = b_0 u + f$$
    where $u$ is the ESC pulse **actually applied**, $b_0$ is the input gain in $(\text{W/s})/\mu s$, and $f$ is the total disturbance (plant pole, load, voltage sag, unmodelled terms) in W/s. The observer is a second-order LESO ($z_1 \approx P$, $z_2 \approx f$, gains $l_1 = 2w_o$, $l_2 = w_o^2$) and the control law is
    $$u = \frac{k_p (r - z_1) - z_2}{b_0}, \qquad k_p \text{ in } 1/s$$
    $k_p$ places the closed-loop pole at $-(1/\tau + k_p)$; the learning derives $k_p = 2/\tau$, i.e. a loop three times faster than the open-loop plant. The full 1000 µs of authority corresponds to a power error of $1000\,b_0/k_p = 500 \times (\text{static gain})$.
*   **Arguments:** Floating-point parameters for $w_o, b_0, K_p, K_d$. $K_d$ is accepted and stored for configuration compatibility but is **not used** by the first-order law. The sampling time step is fixed at 1 ms by the 1 kHz control loop.
*   **Observer input:** `adrc_set_applied()` feeds the LESO the final output pulse each tick, because $u$ may be cut by the pilot's PWM ($PWM_{out} = \min(PWM_{in}, u)$) or by the $\pm$1000 µs actuator limits. Feeding the requested command instead leaves a persistent bias in $z_2$ and saturates the next command.
*   **b0 Learning Mode:** Passing `0` as `<b0>` enables the identification mode. The controller passes the pilot throttle through (with a 1.2× target-power safety cap) while collecting moving averages of power in the 10-50% and 75-100% throttle bands. Three alternating throttle steps (low→high, high→low, low→high) are captured; each step's time constant $\tau_m$ is estimated with a log-linear least-squares fit of $\ln|\text{target} - y(t)|$, which yields a genuine **first-order** time constant, and the median of the three estimates is used. The static gain comes from the band averages, $K = \Delta P/\Delta U$, so the controller derives and saves
    $$b_0 = \frac{K}{\tau_m} = \frac{\Delta P}{\tau_m \Delta U}, \qquad w_c = \frac{2}{\tau_m}, \qquad K_p = w_c, \qquad K_d = 0, \qquad w_o = \min(5 w_c,\ 200)$$
    The $w_o$ clamp keeps $w_o\,dt \le 0.2$ at 1 kHz, which is where a forward-Euler second-order LESO still behaves. Inconsistent step estimates restart the learning automatically. The default `b0 = 0` triggers this on first boot.
*   **Migration note:** changing from the second-order law scales $b_0$ by roughly $\tau$ (a factor ~30-40 for these plants), so a $b_0$ stored by an older firmware is invalid and the identification must be re-run.

#### `ident [run [lambda_ms]] | abort`
*   **Description:** Automatic plant identification. The firmware takes ownership of the ESC output (bypassing $PWM_{out} = \min(PWM_{in}, u)$) and drives a **staircase** of five settled throttle levels, fitting the plant gain $K$, the time constant $\tau$ and the stimulus dead time at every step. On success it derives $\lambda$-tuned gains, applies them and saves them to NVS.
*   **No arguments:** prints the result table of the last run (per level: $u$, settled $P$, $K$, $\tau$, $R^2$, dead time $t_0$), the median $\tau$, $K$ at the target, $\lambda$ and the applied gains.
*   **`run`:** arms a run. **The firmware drives the motor.** Arming condition: the throttle stick must stay below 1200 µs for 1 s (and the input and battery must be valid, so the device will not drive the motor without a live RC link). Moving the stick, an unsafe input, exceeding the 400 W power cap or the 20 s timeout aborts immediately and hands the throttle back to the pilot on the same tick.
*   **`run <lambda_ms>`:** same, with an explicit closed-loop time constant in ms (default: automatic, $\lambda = \max(\tau, 25\,\text{ms})$; clamped to 25–500 ms).
*   **`abort`:** stops a running identification.
*   **Why a staircase and not a pilot slam:** the step is one control tick wide (no human ramp), $t = 0$ is known exactly, each level's settled power is measured *after* it settles instead of using the average of the whole transient as the asymptote, and the actuator's 0–20 ms dead time (one ESC PWM frame) is *fitted* by scanning $t_0 \in [0, 20]$ ms and keeping the best $R^2$, instead of being absorbed into $\tau$.
*   **Timing:** 1 s arming + 600 ms per level + 256 ms capture window per step $\approx$ 4 s of motor run.
*   **Gain mapping (IMC / $\lambda$-tuning):** with $b_0 = K/\tau$,
    $$k_p = \frac{1}{\lambda}, \qquad w_o = \frac{1}{\sqrt{\lambda\tau}}$$
    so $\lambda$ is the only knob: it is the closed-loop time constant. Fits with $R^2 < 0.95$ are discarded and the median of the survivors is used. The 25 ms floor exists because the ESC output PWM has a 20 ms period, so the actuator alone contributes 0–20 ms (mean 10 ms ≈ 90° at 25 Hz) of delay that no amount of observer bandwidth can recover.
*   **Gain selection:** $K$ is taken from the *local* staircase interval that brackets the power target, because the measured plant gain varies ~60% across the throttle range.
*   **Feedforward:** a successful run also arms an inverse-model feedforward table (in RAM only). The control law becomes $u = u_{ff} + \frac{k_p (r - z_1) - z_2}{b_0}$, with $u_{ff}$ interpolated from the identified $P(u)$ map and rescaled by $V_{ref}/V_{bus}$. Because $u_{ff}$ is open loop it costs no phase margin, and $z_2$ absorbs any error in it, so a stale map degrades the transient but never the steady state. The table is cleared when a new run starts and is only used while the target lies inside the identified power range; targets outside it fall back to feedback only.
*   **Interaction with learning mode:** a successful identification sets $b_0 \neq 0$, clears learning mode and stages the result as `LEARNING_STAGE_DONE`.
*   **Streaming:** while a capture window is open, raw 1 kHz samples are also emitted as stream frame type 3 so a fit can be verified offline (see §4.2).

#### `target <power_watts>`
*   **Description:** Sets the active power target limit.
*   **Arguments:** Floating-point power target in Watts. Saves to NVS immediately.

#### `set_team <number> <name>`
*   **Description:** Configures the team identification parameters.
*   **Arguments:**
    *   `<number>`: Unsigned integer team number.
    *   `<name>`: Character string (up to 31 characters) representing the team name.
*   **Storage:** Saves to NVS immediately.

#### `set_pin <pin_code>`
*   **Description:** Updates the device's 6-digit PIN code.
*   **Arguments:** A 6-character string representing the security PIN.
*   **Storage:** Saves to NVS immediately.

#### `stream <on|off>` | `stream csv <on|off>`
*   **Description:** Activates or deactivates the 10 Hz real-time CSV telemetry streaming on the default console port (port 1). `stream csv <on|off>` is the explicit spelling of the same thing.

#### `stream bin <on|off> [period_ms]`
*   **Description:** Activates or deactivates the binary telemetry stream on the **second CDC ACM port** (port 2, see §4).
*   **Arguments:**
    *   `<on|off>`: enables or disables the stream. Normally open this port **before** enabling, otherwise the first frames are dropped.
    *   `[period_ms]`: optional frame period, `1`–`48`, default `4`. Because the stream is fed by the 1 kHz control loop, this is also the number of samples per frame (4 ms → 4 samples/frame at 250 frames/s).
*   **Behaviour:** Disabling only stops new samples; a frame already in flight is completed so the host never sees a truncated frame. Enabling starts from an empty ring, so the host sees current data, not a stale backlog.

#### `stream status`
*   **Description:** Prints the state of both streams plus the binary stream diagnostics: frame and sample counters (sent/dropped), mid-frame TX stalls and framing errors. Use it to tell "the host is not reading" (drops rising, stalls rising) from "the device is not producing" (counters flat).

#### `readings`
*   Description: Triggers a single print of the current telemetry values in CSV format.

---

## 4. Binary Telemetry Stream (Second USB CDC ACM Port)

### 4.1 Motivation and port topology

The console port must stay interactive, and in this build it is shared with *all* log output (the log backend is the shell backend, `CONFIG_SHELL_LOG_BACKEND=y`), which makes it line-oriented, DTR-gated and unsuitable for binary traffic. Instead of multiplexing binary data into it, the device instantiates a **second CDC ACM interface** and dedicates a port to telemetry.

| Property | Port 1 — console/shell | Port 2 — telemetry |
|---|---|---|
| Devicetree node | `board_cdc_acm_uart` | `stream_cdc_acm_uart` |
| USB interface numbers | 0 (control) + 1 (data) | 2 (control) + 3 (data) |
| Linux | `/dev/ttyACM0` | `/dev/ttyACM1` |
| Windows device instance | `...&MI_00` | `...&MI_02` |
| Carries | shell, `printf`, LOG, 10 Hz CSV | binary frames only |
| Shell available | yes | no |

Both interfaces belong to **one USB device**, therefore they share a single `idVendor`/`idProduct` (`CONFIG_USB_DEVICE_VID=0x2FE3`, `CONFIG_USB_DEVICE_PID=0x0100`) and one serial number; a VID/PID pair cannot be assigned per interface. Distinguish the ports by interface number:

```
# /etc/udev/rules.d/60-pm100.rules
SUBSYSTEM=="tty", ATTRS{idVendor}=="2fe3", ATTRS{idProduct}=="0100", \
  ENV{ID_USB_INTERFACE_NUM}=="00", SYMLINK+="pm100_shell"
SUBSYSTEM=="tty", ATTRS{idVendor}=="2fe3", ATTRS{idProduct}=="0100", \
  ENV{ID_USB_INTERFACE_NUM}=="02", SYMLINK+="pm100_stream"
```

Zephyr's `cdc_interface_config()` rebases the interface numbers per instance at build time, so the device enumerates as a single configuration with two IADs (interfaces 0-1 and 2-3). The device never reads the telemetry port, so the host may open it without asserting DTR. Baud rate is meaningless for both ports: USB CDC stores the host's line coding but no clock is derived from it.

### 4.2 Wire format

Little-endian, packed, no padding. `frame := header payload`.

**Header — 8 bytes**

| Offset | Type | Field | Notes |
|---|---|---|---|
| 0 | `u8` | `magic` | always `0xA5` |
| 1 | `u8` | `version` | currently `0x01` |
| 2 | `u8` | `type` | `1` = samples, `2` = controller snapshot, `3` = identification capture |
| 3 | `u16` | `seq` | frame counter, +1 per frame, wraps at 65536 |
| 5 | `u8` | `count` | items in the payload (samples 1..48, snapshot 1) |
| 6 | `u16` | `len` | payload length in bytes |

**Payload type 1 — `pm100_stream_sample`, 44 bytes per item**

| Offset | Type | Field | Unit / scaling | Meaning |
|---|---|---|---|---|
| 0 | `u32` | `t_ms` | ms | uptime (wraps after ~49.7 days) |
| 4 | `i32` | `e_j` | J | accumulated energy |
| 8 | `i32` | `z1_mw` | mW | LESO $z_1$ — estimated power |
| 12 | `i32` | `z2_mws` | mW/s | always 0 (first-order observer has no $\dot P$ state) |
| 16 | `i32` | `z3_mws` | mW/s | disturbance estimate $f$ (2nd LESO state) |
| 20 | `u16` | `v_cv` | 10 mV (`2550` = 25.50 V) | bus voltage |
| 22 | `i16` | `i_ca` | 10 mA (`1250` = 12.50 A) | current |
| 24 | `i16` | `y_dw` | 0.1 W | measured power — controller input $y$ |
| 26 | `u16` | `pmax_w` | W | peak power since boot |
| 28 | `i16` | `tgt_dw` | 0.1 W | power target — reference $r$ |
| 30 | `u16` | `pwm_in` | µs | pilot throttle input |
| 32 | `u16` | `pwm_out` | µs | applied ESC pulse $\min(PWM_{in}, u)$ |
| 34 | `u16` | `pwm_ctrl` | µs | ADRC effort after clamping |
| 36 | `i16` | `pwm_ctrl_raw` | µs | ADRC effort **before** clamping (wind-up) |
| 38 | `u8` | `state` | enum | `ctrl_state`, same numbering as the CSV |
| 39 | `u8` | `flags` | bitfield | see below |
| 40 | `u8[4]` | `_rsvd` | — | reserved, keeps the item 4-byte aligned |

`flags` bits:

| Bit | Mask | Name | Meaning |
|---|---|---|---|
| 0 | `0x01` | `INPUT_VALID` | throttle pulse inside 850–2100 µs |
| 1 | `0x02` | `BATTERY_VALID` | bus voltage ≥ 5.0 V |
| 2 | `0x04` | `SAFE` | both of the above, so the control law ran |
| 3 | `0x08` | `LEARNING` | b0 identification mode active |
| 4 | `0x10` | `LEARN_POWER_CUT` | learning safety cap tripped |
| 5 | `0x20` | `ADRC_SATURATED` | raw effort was clamped to 1000–2000 µs |
| 6 | `0x40` | `SENSOR_ERROR` | INA226 read failed this tick (v/i forced to 0) |
| 7 | `0x80` | `BYPASS` | bypass switch ≥ 1500 µs: limiter off, throttle passes straight through |

> `z1_mw`, `z2_mws`, `z3_mws` and `pwm_ctrl_raw` are only meaningful on ticks where the control law actually ran (`SAFE` set, `LEARNING` clear and `BYPASS` clear); they hold the previous value otherwise.

**Payload type 2 — `pm100_stream_meta`, 84 bytes** (sent once per second *and* immediately after any parameter change)

| Offset | Type | Field | Unit | Notes |
|---|---|---|---|---|
| 0 | `f32` | `wo` | rad/s | observer bandwidth |
| 4 | `f32` | `b0` | (W/s) per µs | input gain |
| 8 | `f32` | `kp` | 1/s | loop gain |
| 12 | `f32` | `kd` | — | UNUSED by the first-order law (legacy field) |
| 16 | `f32` | `l1` | — | $2 w_o$ |
| 20 | `f32` | `l2` | — | $w_o^2$ |
| 24 | `f32` | `l3` | — | always 0 (no third LESO state) |
| 28 | `f32` | `target_power` | W | active power target |
| 32 | `f32` | `shunt_mohm` | mΩ | configured shunt |
| 36 | `f32` | `dt` | s | control period |
| 40 | `u32` | `uptime_ms` | ms | when the snapshot was taken |
| 44 | `u32` | `team_number` | — | team / controller number |
| 48 | `char[32]` | `team_name` | — | NUL-padded |
| 80 | `u8` | `learning_stage` | enum | `learning_stage` |
| 81 | `u8[3]` | `_rsvd` | — | reserved |

**Payload type 3 — `pm100_stream_ident`, 12 bytes per item** (only emitted while `pm100 ident run` executes)

| Offset | Type | Field | Unit | Notes |
|---|---|---|---|---|
| 0 | `u32` | `t_ms` | ms | uptime of the sample |
| 4 | `u16` | `cmd_us` | µs | throttle the firmware commanded |
| 6 | `i16` | `p_dw` | 0.1 W | measured power ($y$) |
| 8 | `u8` | `level` | — | staircase level index (`0`–`4`) |
| 9 | `u8` | `flags` | bitfield | bit 0 `PM100_IDENT_FLAG_STEP` = first sample of a capture window, i.e. $t = 0$ for that fit |
| 10 | `u8[2]` | `_rsvd` | — | reserved |

> A capture window is 256 samples at 1 kHz, starting at the tick the firmware steps to a new level. Because the ESC only sees a new pulse width at the next 20 ms PWM frame boundary, the true plant input is delayed by 0–20 ms relative to $t = 0$; that is exactly the dead time the firmware scans for. Reconstructing $\tau$ from this dump requires the same $t_0$ scan, and using the *settled* power of each level (not the window average) as the asymptote.

**Reference Python decoder** (the sizes are enforced at compile time by the `BUILD_ASSERT`s in `src/stream.h` / `src/stream.c`):
```python
import struct

HDR    = struct.Struct("<BBBHBH")               # 8 B
SAMPLE = struct.Struct("<IiiiihhHhHHHhBB4x")    # 44 B
META   = struct.Struct("<10fII32sB3x")          # 84 B
IDENT  = struct.Struct("<IHhBB2x")              # 12 B

TYPE_SAMPLES, TYPE_META, TYPE_IDENT = 1, 2, 3
MAGIC, VERSION = 0xA5, 0x01

def parse(fh):
    """Yield (type, tuple) per frame; resynchronises on garbage."""
    buf = bytearray()
    while True:
        chunk = fh.read(4096)
        if not chunk:
            return
        buf += chunk
        while True:
            i = buf.find(MAGIC)
            if i < 0:
                del buf[:max(0, len(buf) - 1)]   # keep a possibly split magic
                break
            del buf[:i]
            if len(buf) < HDR.size:
                break
            magic, ver, ftype, seq, count, plen = HDR.unpack_from(buf)
            item = {TYPE_SAMPLES: SAMPLE, TYPE_META: META, TYPE_IDENT: IDENT}.get(ftype)
            if ver != VERSION or item is None or plen != count * item.size:
                del buf[:1]                       # false magic, resync
                continue
            if len(buf) < HDR.size + plen:
                break
            payload = buf[HDR.size:HDR.size + plen]
            for n in range(count):
                yield ftype, item.unpack_from(payload, n * item.size)
            del buf[:HDR.size + plen]
```

### 4.3 Host parser rules

1. Scan for `0xA5`; accept a frame only if `version == 1` and `len == count × item_size` — that is enough to resynchronise after any noise.
2. A jump in `seq` means whole **frames** were lost (e.g. the host stopped reading).
3. A jump in `t_ms` means individual **samples** were dropped on-device (ring overflow).
4. No per-frame CRC is needed: USB bulk already carries a link-layer CRC with retransmission. `magic` + `len` + `seq` cover framing and loss detection.

### 4.4 Rates, latency and bandwidth

| Metric | Value |
|---|---|
| Sample rate | 1000 samples/s (every 1 kHz control tick) |
| Default period | 4 ms → 4 samples/frame, 250 frames/s |
| Frame size (`period_ms = 4`) | 8 + 4 × 44 = 184 B |
| Sample stream | ≈46 kB/s (≈368 kbit/s, ≈3 % of Full-Speed USB) |
| Snapshot stream | 92 B/s (1 Hz) |
| Latency | ≈ `period_ms` + USB transfer + host read |
| Ring slack | 8 KiB ≈ 186 samples ≈ 186 ms of host stall absorbed |

Total bandwidth stays between ≈44 and ≈52 kB/s for any `period_ms` (the 8-byte header is negligible), so the knob only trades **latency against frame count**: `period_ms = 1` gives ≈1 ms latency at 1000 frames/s, `period_ms = 48` gives ≈48 ms at ≈21 frames/s.

For comparison, the 10 Hz CSV on the console port is ≈0.7 kB/s; streaming that same CSV at 1 kHz would be ≈70 kB/s *and* would be limited by `%f` software-double formatting rather than by the wire.

### 4.5 Build configuration

`prj.conf`:
```
CONFIG_USB_CDC_ACM_RINGBUF_SIZE=4096
```
The CDC ACM ring buffer size is global, i.e. it applies to TX **and** RX of **both** instances (16 kB of RAM). It is much larger than the largest frame (2120 B) so that a whole frame is normally accepted by a single `uart_fifo_fill()` call.

`boards/xiao_ble_nrf52840.overlay`:
```dts
&zephyr_udc0 {
	stream_cdc_acm_uart: stream_cdc_acm_uart {
		compatible = "zephyr,cdc-acm-uart";
	};
};
```

Endpoint budget: each CDC ACM instance takes 2 IN + 1 OUT → 4 IN + 2 OUT of the 7 IN / 7 OUT the nRF52840 USBD exposes (EP0 bidir aside).

### 4.6 Implementation map

| File | Role |
|---|---|
| `src/stream.h` | Wire format definition and public API — the reference for the desktop parser |
| `src/stream.c` | 8 KiB SPSC ring, record framing, frame assembly, `uart_fifo_fill()` TX, Thread 4 |
| `src/control.c` | Per-tick sample production, controller snapshot, `g_adrc.u_raw`, the identification state machine and the feedforward map |
| `src/main.c` | `stream_init()` call and shell commands (`stream`, `pm100 ident`) |
| `boards/xiao_ble_nrf52840.overlay` | Second `zephyr,cdc-acm-uart` node |
| `prj.conf` | CDC ACM ring buffer size |
| `CMakeLists.txt` | Adds `src/stream.c` to the build |

### 4.7 Error handling

| Condition | Behaviour |
|---|---|
| Second port missing from the devicetree | `stream_init()` returns `-ENODEV`, stream stays disabled, everything else works |
| Host not reading the port | Frames are dropped (counted) instead of written partially, so the host never sees a truncated frame; the ring then overflows and samples are dropped (counted) |
| USB back-pressure mid-frame | The frame is completed before anything else is written, so frames stay frame-aligned |
| Ring misuse / torn record | Detected by the record length check, ring is reset by its owner, `corrupt_records` is bumped |

Diagnostics are exposed with `stream status` (see §3).

---

## 5. Bluetooth BLE Service Specification

To optimize bandwidth and power consumption, the device exposes telemetry parameters using standard Bluetooth SIG 16-bit characteristics and compact, scaled binary integers instead of ASCII CSV strings. Custom metadata and raw signals employ dedicated 128-bit characteristics.

### Custom GATT Service

The PM100 Power Limiter GATT Service is defined by the following custom 128-bit Service UUID:
*   **PM100 Service UUID:** `E20A1A00-473B-4444-9F6D-BE083A8BD92D`

### BLE Link Encryption, Bonding & PIN-Passkey Security

For operator privacy and security, all telemetry characteristics require **Encrypted Link Pairing with Man-in-the-Middle (MITM) protection** and **Persistent Bonding**.

*   **Passkey Pairing:** The 6-digit PIN code configured in the storage `PIN_code` structure acts as the Bluetooth pairing password (Passkey).
*   **Encrypted Attributes:** All GATT characteristics are guarded with `BT_GATT_PERM_READ_ENCRYPT` permissions. If a client attempts to read or subscribe to telemetry without pairing first, the BLE stack automatically halts the request, triggers the numeric passcode entry on the client's screen, and encrypts the communication link.
*   **Persistent Bonding:** Pairing is upgraded to a permanent **Bond**. Pairing keys (bonding keys) and client configuration descriptor (CCCD) subscriptions are saved persistently to flash via the Settings Subsystem. When a previously paired client reconnects, the connection is encrypted automatically without prompting the user to enter the passkey again.
*   **Bond Capacity and Rotation:** To protect resource consumption in flash, the system maintains up to 5 paired devices. If the bond table is full and a new device attempts to bond, the Bluetooth stack automatically deletes and replaces the oldest bond keys (Least Recently Used) to prevent pairing failures.

### Dynamic Device Name Composition

The BLE device name is compiled dynamically at runtime during startup using the following pattern:
$$\text{Device Name} = \text{team\_name}\_\text{team\_number}\_\text{MAC\_last\_4}$$
*Example Compiled Name:* `TeamFalcon_1234_F1A2`

*   `team_name`: String loaded from NVS.
*   `team_number`: Unsigned integer loaded from NVS.
*   `MAC_last_4`: The last 4 hexadecimal characters of the Bluetooth MAC address of the Seeed Studio Xiao BLE.

### Telemetry Characteristics & Standard UUID Mapping

| Parameter | Standard GATT Name | UUID (16-bit or 128-bit) | Properties | Binary Format & Scaling | Bandwidth Size |
|---|---|---|---|---|---|
| **Voltage** | Voltage | `0x2B18` (16-bit) | `NOTIFY`, `READ` | `uint16_t` in Millivolts (mV) (e.g. $11.8\text{V} \rightarrow 11800$) *(Requires Encryption)* | 2 Bytes |
| **Current** | Current | `0x2B17` (16-bit) | `NOTIFY`, `READ` | `uint16_t` in Milliamperes (mA) (e.g. $10.2\text{A} \rightarrow 10200$) *(Requires Encryption)* | 2 Bytes |
| **Energy** | Energy (Total Cons.) | `0x2B06` (16-bit) | `NOTIFY`, `READ` | `uint32_t` in Joules (J) (e.g. $450.2\text{J} \rightarrow 450$) *(Requires Encryption)* | 4 Bytes |
| **Uptime** | Time ms | `0x2A2B` (16-bit) | `READ` | `uint32_t` in milliseconds (ms) from startup *(Requires Encryption)* | 4 Bytes |
| **PWM Signals** | PWM Signals State | `E20A1A03-473B-4444-9F6D-BE083A8BD92D` | `NOTIFY`, `READ` | Array of 3x `uint16_t` representing $PWM_{in}$, $PWM_{out}$, $PWM_{ctrl}$ in microseconds *(Requires Encryption)* | 6 Bytes |
| **Team Name** | Team Name | `E20A1A04-473B-4444-9F6D-BE083A8BD92D` | `READ` | UTF-8 encoded string (up to 32 bytes, null-terminated) *(Requires Encryption)* | Up to 32 Bytes |
| **Team Number** | Team Number | `E20A1A05-473B-4444-9F6D-BE083A8BD92D` | `READ` | `uint32_t` representing the unique team index *(Requires Encryption)* | 4 Bytes |
| **White Blink Cmd**| White Blink Trigger | `E20A1A06-473B-4444-9F6D-BE083A8BD92D` | `WRITE` | 1-byte Boolean (`0x01` to trigger 10x white blinks) *(Requires Encryption)* | 1 Byte |
| **Peak Power** | Peak Power (since boot) | `E20A1A08-473B-4444-9F6D-BE083A8BD92D` | `NOTIFY`, `READ` | `uint32_t` in Milliwatts (mW) representing the peak power measured since boot (e.g. $600.0\text{W} \rightarrow 600000$) *(Requires Encryption)* | 4 Bytes |
| **Control State** | Control State | `E20A1A07-473B-4444-9F6D-BE083A8BD92D` | `NOTIFY`, `READ` | `uint8_t` representing the `ctrl_state` enum value *(Requires Encryption)* | 1 Byte |

### Bandwidth Comparison & Optimization

*   **ASCII CSV Telemetry Stream:** ~55 bytes per packet $\times$ 10Hz = **550 bytes/second** (4400 bps).
*   **Split Binary Integer Stream:** 19 bytes total per packet $\times$ 10Hz = **190 bytes/second** (1520 bps).
*   **Net Bandwidth Saving:** **~65% reduction** in radio airtime, lowering power consumption and eliminating frame fragmentation. Static identification data (Team Name and Number) are read once on connection, avoiding unnecessary periodic bandwidth consumption.

---

## 6. Implementation Guidelines (AI Instructions)

1.  **Scope Restrictions:**
    *   Only modify files inside the `/src` folder.
    *   **Do not** make any modifications to files within `/src/lipe` or outside of `/src` (with the exception of verifying headers/interfaces).
    *   **Documented exception — binary telemetry stream (§4):** adding the second USB CDC ACM port necessarily touches build/configuration files, namely `boards/xiao_ble_nrf52840.overlay` (the new `zephyr,cdc-acm-uart` node), `prj.conf` (`CONFIG_USB_CDC_ACM_RINGBUF_SIZE`) and `CMakeLists.txt` (adding `src/stream.c`). Keep such edits to the minimum the feature requires and do not extend them to unrelated settings.
2.  **Documentation Standards:**
    *   Provide brief, clear documentation headers for all newly created functions.
    *   Follow the naming conventions already present in the codebase.
3.  **Concurrency & Safety:**
    *   Utilize Zephyr thread primitives (e.g., `K_THREAD_DEFINE`) to schedule the four threads.
    *   Implement basic thread safety (e.g., mutexes, atomic flags, or volatile variables) for variables shared across Thread 1, Thread 2, Thread 3, and Thread 4.
    *   Respect the producer/consumer contract of the telemetry stream: `stream_push_sample()`, `stream_push_meta()` and `stream_push_ident()` may only be called from Thread 1 (the sole producer), the sample ring is a lock-free SPSC structure, and `ring_buf_reset()` may only run on the producer side (gated by `g_stream_reset_req`).
    *   Any feature that lets the firmware drive the motor on its own (like the `pm100 ident` staircase) must keep an unconditional, single-tick abort path: an unsafe input, a stick movement above the idle threshold, a power cap or a timeout must return the throttle to the pilot's $\min(PWM_{in}, u)$ path immediately, without waiting for the current phase to finish.

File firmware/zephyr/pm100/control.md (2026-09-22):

# ADRC Control Analysis and Parameter Derivation

This document details the theoretical derivation and practical tuning of the Active Disturbance Rejection Control (ADRC) parameters implemented in the PM100 power limiter firmware. This design is optimized for a small brushless DC (BLDC) motor propulsion system on an RC aircraft, controlled via Electronic Speed Controller (ESC) PWM signals ($1000\,\mu\text{s}$ to $2000\,\mu\text{s}$) under a **4S (14.8V) to 6S (22.2V) LiPo** battery pack.

---

## 1. System Modeling and Input-Output Mapping

In a second-order ADRC formulation, the system acceleration of the output variable $y(t)$ (Active Power in Watts) is coupled to the control input $u(t)$ (ESC PWM pulse width in microseconds) through:

$$\ddot{y}(t) = b_0 u(t) + f(t, y, \dot{y}, d)$$

Where:
*   **Output ($y$):** Active power $P(t)$ in Watts (measured by the high-side INA226 power monitor). Nominal target limit set to **$600\,\text{W}$**.
*   **Control Input ($u$):** Output throttle command $PWM_{out}$ in microseconds. Absolute physical bounds are $[1000\,\mu\text{s}, 2000\,\mu\text{s}]$, representing zero to full throttle.
*   **Total Disturbance ($f$):** Aggregates all internal unmodeled dynamics (motor/ESC efficiency curves, rotor friction, heat losses) and external disturbances (aerodynamic propeller load torque variations, battery voltage sag under high discharge rates).
*   **Control Gain Factor ($b_0$):** Denotes the estimated instantaneous sensitivity of power acceleration $\ddot{P}(t)$ to changes in the PWM input signal.

---

## 2. Derivation of the Gain Factor ($b_0$) first guess

To estimate a realistic initial value for $b_0$, we analyze the step response characteristics of a small RC aircraft BLDC motor:

1.  **Mechanical Time Constant ($\tau_m$):** Small BLDC motors (e.g., 2212 or 2814 stator size) paired with lightweight carbon fiber or plastic propellers exhibit highly responsive mechanical time constants, typically:
    $$\tau_m \approx 0.1\,\text{seconds}\quad (100\,\text{ms})$$
2.  **Open-Loop Bandwidth ($w_m$):**
    $$w_m = \frac{1}{\tau_m} \approx 10\,\text{rad/s}$$
3.  **Step Acceleration ($\ddot{P}$):**
    When applying a full-throttle step command from rest (delta input of $\Delta u = 1000\,\mu\text{s}$), the motor accelerates to its maximum power rating ($P_{max} \approx 800\,\text{W}$ on 4S to 6S setups) in approximately $\tau_m$ seconds. The initial second-order acceleration rate is approximated as:
    $$\ddot{P}(0) \approx \frac{P_{max}}{\tau_m^2} = \frac{800\,\text{W}}{(0.1\,\text{s})^2} = 80,000\,\frac{\text{W}}{\text{s}^2}$$
4.  **Derivation of $b_0$:**
    The control gain $b_0$ acts as the scaling coefficient mapping input microseconds directly to output power acceleration:
    $$b_0 \approx \frac{\ddot{P}(0)}{\Delta u} = \frac{80,000\,\text{W/s}^2}{1000\,\mu\text{s}} = 80.0\,\frac{\text{W}}{\text{s}^2\cdot\mu\text{s}}$$

To ensure that the state observer (LESO) does not experience initial peaking or cause excessive control action saturation, we select a conservative and physically stable first guess:
$$b_0 = 50.0\,\frac{\text{W}}{\text{s}^2\cdot\mu\text{s}}$$

---

## 3. Bandwidth-Based Controller Tuning ($K_p$, $K_d$)

Using **Gao's Bandwidth Parameterization** for a second-order system, we select a closed-loop controller bandwidth $w_c$ that balances rapid command tracking with high noise rejection.

1.  **Selection of Controller Bandwidth ($w_c$):**
    We select $w_c \approx 20\,\text{rad/s}$ (which is 2 times faster than the open-loop motor bandwidth of $10\,\text{rad/s}$ and well below the Nyquist limit of the 1kHz control loop).
2.  **Proportional Gain ($K_p$):**
    $$K_p = w_c^2 = 20^2 = 400.0$$
3.  **Derivative Gain ($K_d$):**
    $$K_d = 2 w_c = 2 \times 20 = 40.0$$

*This critical parameterization ($K_d = 2\sqrt{K_p}$) guarantees that the tracking loop remains critically damped ($\zeta = 1.0$), eliminating throttle overshoot during rapid pilot command transitions.*

---

## 4. Extended State Observer Tuning ($w_o$)

The **Linear Extended State Observer (LESO)** is responsible for dynamically estimating the measured power $z_1(t) \approx P(t)$, its derivative $z_2(t) \approx \dot{P}(t)$, and the total system disturbance state $z_3(t) \approx f(t)$ at a 1kHz sampling rate.

*   **Bandwidth Rule of Thumb:** To ensure fast and stable estimation without phase lag, the observer bandwidth $w_o$ should be set 5 times faster than the controller bandwidth:
    $$w_o = 5 \times w_c = 100.0\,\text{rad/s}$$
*   **Observer Pole Placement:** The three poles of the LESO are placed at $-w_o$, generating continuous-time Euler integration gains mapping to:
    *   $l_1 = 3 w_o$
    *   $l_2 = 3 w_o^2$
    *   $l_3 = w_o^3$

---

## 5. Practical Tuning Guidelines for Propulsion Engineers

When deploying this ADRC loop on your physical 4S to 6S aircraft propulsion rig, use the following calibration guidelines:

| Symptom / Observation | Root Cause | Corrective Action |
|---|---|---|
| High-frequency motor "hissing" or ESC jittering on standby | $w_o$ is too high, making the observer oversensitive to INA226 current sensor noise. | Decrease $w_o$ in steps of 10 (e.g., from 100 down to 70) to filter the noise. |
| Power limiting reacts too slowly, allowing initial overshoot past 600W. | Controller bandwidth $w_c$ is too low or system gain $b_0$ is overestimated. | Decrease $b_0$ (e.g., from 50 down to 30) or increase $w_c$ to scale up $K_p$ and $K_d$. |
| Motor is jittery or exhibits jerky thrust behavior on rapid throttle changes. | $b_0$ is underestimated, causing the controller to output excessively large corrective steps. | Increase $b_0$ (e.g., from 50 up to 80 or 100) to dampen setpoint error sensitivity. |
| Voltage sag on 6S LIPO battery causes sudden thrust drop under load. | LESO is slow to estimate the voltage drop's effect on motor torque. | Increase $w_o$ (e.g., from 100 to 120) to accelerate disturbance estimation. |

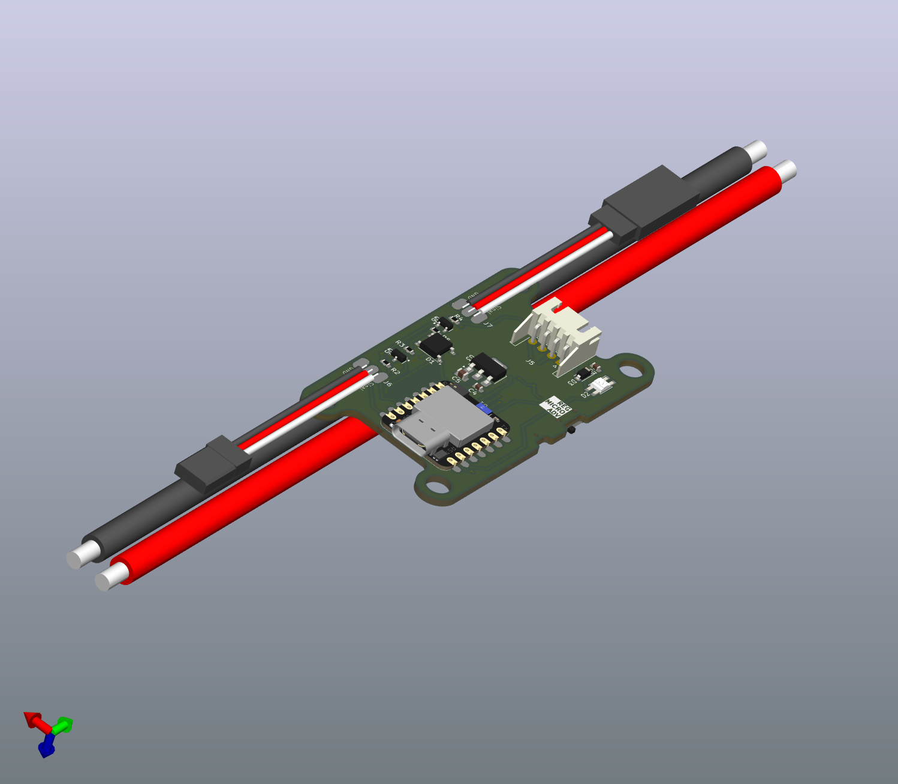
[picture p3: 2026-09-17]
hardware/pm100-xiao/pm100-iso.png

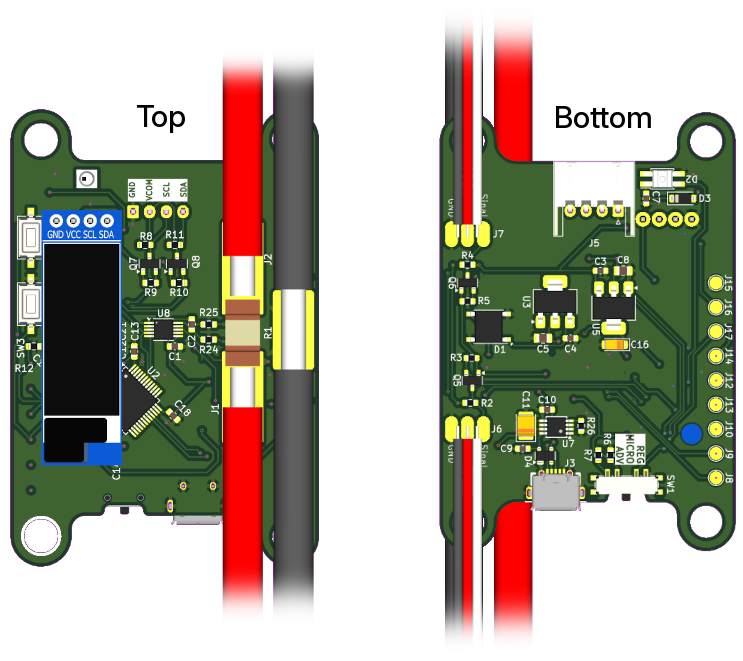
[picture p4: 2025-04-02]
hardware/pm100-xiao/pm100_img.png

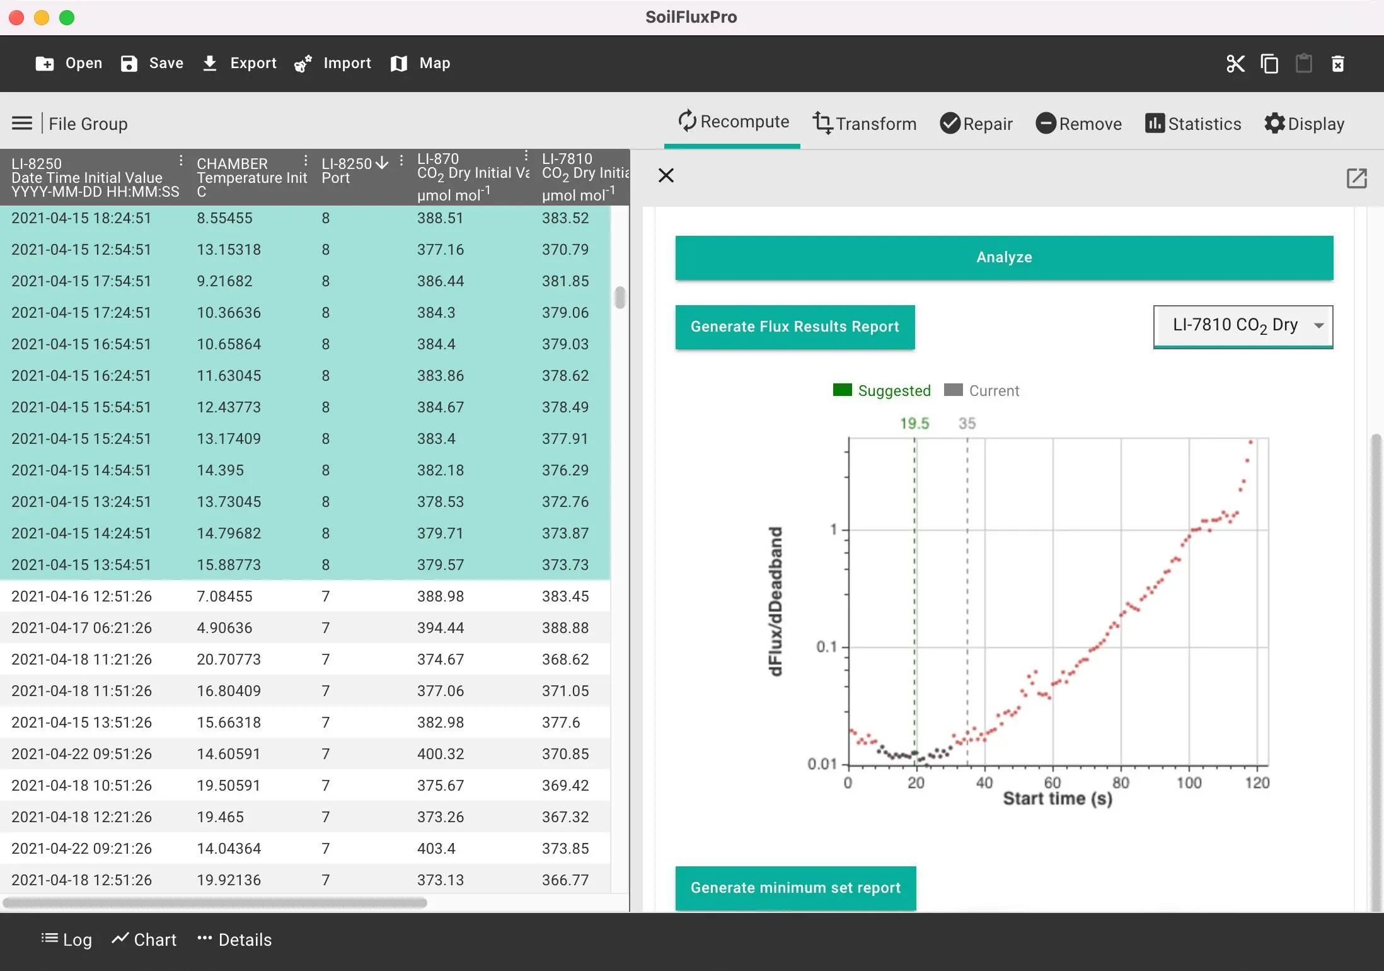
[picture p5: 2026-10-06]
hardware/pm100-xiao/SFP-deadband.webp

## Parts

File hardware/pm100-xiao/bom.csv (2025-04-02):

Reference | Value | Datasheet | Footprint | Qty | DNP
C1,C2,C3,C4,C7,C9,C10,C12,C13,C14,C15,C18 | 0.1u | ~ | Capacitor_SMD:C_0603_1608Metric | 12
C5,C8,C11 | 10u | ~ | -- mixed values -- | 3
C16 | 4.7u | ~ | Capacitor_Tantalum_SMD:CP_EIA-3216-18_Kemet-A | 1
C17 | 1u | ~ | Capacitor_SMD:C_0603_1608Metric | 1
C19,C20 | 20p | ~ | Capacitor_SMD:C_0603_1608Metric | 2
C21,C22 | 10p | ~ | Capacitor_SMD:C_0603_1608Metric | 2
D1 | ABS6 | https://diotec.com/tl_files/diotec/files/pdf/datasheets/abs2.pdf | Diode_SMD:Diode_Bridge_Diotec_ABS | 1
D2 | SK6812MINI | https://cdn-shop.adafruit.com/product-files/2686/SK6812MINI_REV.01-1-2.pdf | Sigma Footprints:SK6812MINI-E | 1
D3 | 1N4148W | https://www.vishay.com/docs/85748/1n4148w.pdf | Diode_SMD:D_SOD-123 | 1
D4 | PRTR5V0U2X | https://assets.nexperia.com/documents/data-sheet/PRTR5V0U2X.pdf | Package_TO_SOT_SMD:SOT-143 | 1
J1 | VCC-BATT | ~ | footprints:HV_CONN_01x01_pad_6.2x12mm | 1
J2 | VCC-ESC | ~ | footprints:HV_CONN_01x01_pad_6.2x12mm | 1
J3 | USB_B_Micro | ~ | footprints:47589-1001 | 1
J4 | GND-BATT | ~ | footprints:HV_CONN_01x01_pad_6.2x12mm | 1
J5 | UART | ~ | Connector_JST:JST_XH_S4B-XH-A-1_1x04_P2.50mm_Horizontal | 1
J6 | RECEIVER | ~ | Sigma Footprints:SolderWire_SMD_3 | 1
J7 | ESC | ~ | Sigma Footprints:SolderWire_SMD_3 | 1
J8 | SWDIO | ~ | TestPoint:TestPoint_Pad_D2.0mm | 1
J9 | SWCLK | ~ | TestPoint:TestPoint_Pad_D2.0mm | 1
J10 | NRST | ~ | TestPoint:TestPoint_Pad_D2.0mm | 1
J11 | Display | ~ | Sigma Footprints:OLED_0.91_128x32 | 1
J12 | USART2-TX | ~ | TestPoint:TestPoint_Pad_D2.0mm | 1
J13 | USART2-RX | ~ | TestPoint:TestPoint_Pad_D2.0mm | 1
J14 | BOOT0 | ~ | TestPoint:TestPoint_Pad_D2.0mm | 1
L1 | L_Small | ~ | Inductor_SMD:L_0603_1608Metric | 1
Q5,Q6,Q7,Q8 | BSS138 | https://www.onsemi.com/pub/Collateral/BSS138-D.PDF | Package_TO_SOT_SMD:SOT-23 | 4
R1 | R_Shunt | ~ | footprints:MSRSF3920P | 1
R2,R3,R4,R5,R6,R7,R8,R9,R10,R11,R12 | 10k | ~ | Resistor_SMD:R_0603_1608Metric | 11
R24,R25 | 1 | ~ | Resistor_SMD:R_0603_1608Metric | 2
R26 | 400 | ~ | Resistor_SMD:R_0603_1608Metric | 1
R27 | 390 | ~ | Resistor_SMD:R_0603_1608Metric | 1
SW1 | CLASSE | ~ | Button_Switch_SMD:SW_SP3T_PCM13 | 1
U2 | STM32L052C6Tx | https://www.st.com/resource/en/datasheet/stm32l052c6.pdf | Package_QFP:LQFP-48_7x7mm_P0.5mm | 1
U3 | LD1117S50TR_SOT223 | http://www.st.com/st-web-ui/static/active/en/resource/technical/document/datasheet/CD00000544.pdf | Package_TO_SOT_SMD:SOT-223-3_TabPin2 | 1
U5 | LD1117S33TR_SOT223 | http://www.st.com/st-web-ui/static/active/en/resource/technical/document/datasheet/CD00000544.pdf | Package_TO_SOT_SMD:SOT-223-3_TabPin2 | 1
U7 | TPS2113A | https://www.ti.com/lit/ds/symlink/tps2113a.pdf?ts=1597267193821 | Package_SO:TSSOP-8_3x3mm_P0.65mm | 1
U8 | INA226 | http://www.ti.com/lit/ds/symlink/ina226.pdf | Package_SO:VSSOP-10_3x3mm_P0.5mm | 1
Y1 | 32.768khz | ~ | Crystal:Crystal_SMD_3215-2Pin_3.2x1.5mm | 1
Y2 | 8mhz | ~ | Crystal:Crystal_SMD_3215-2Pin_3.2x1.5mm | 1

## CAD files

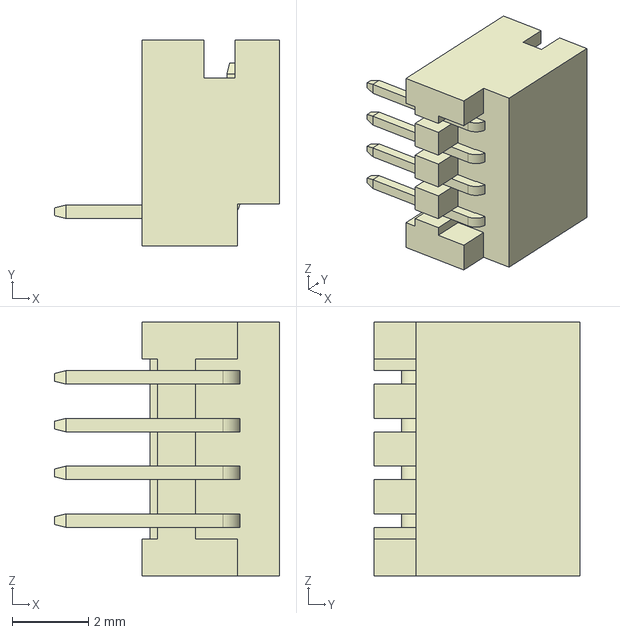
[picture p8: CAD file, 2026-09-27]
hardware/pm100-xiao/3d/DF13-4P-1.25DS.stp
5.90 x 5.40 x 6.65 mm

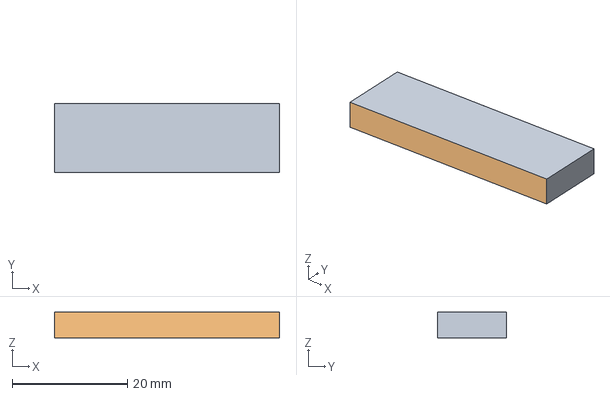
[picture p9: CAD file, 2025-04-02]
hardware/pm100-xiao/Suporte_tela_OLED.FCStd
39.0 x 12.0 x 4.50 mm
PCB_OLED
CopyPad

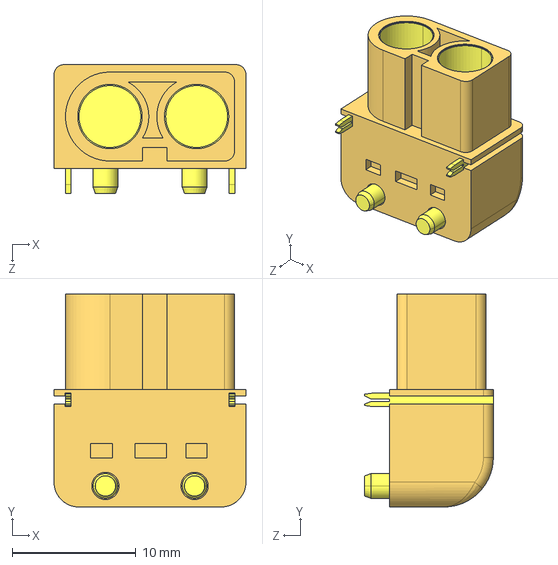
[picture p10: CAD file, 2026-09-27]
hardware/pm100-xiao/3d/XT60PW-F.STEP
15.5 x 17.2 x 10.4 mm

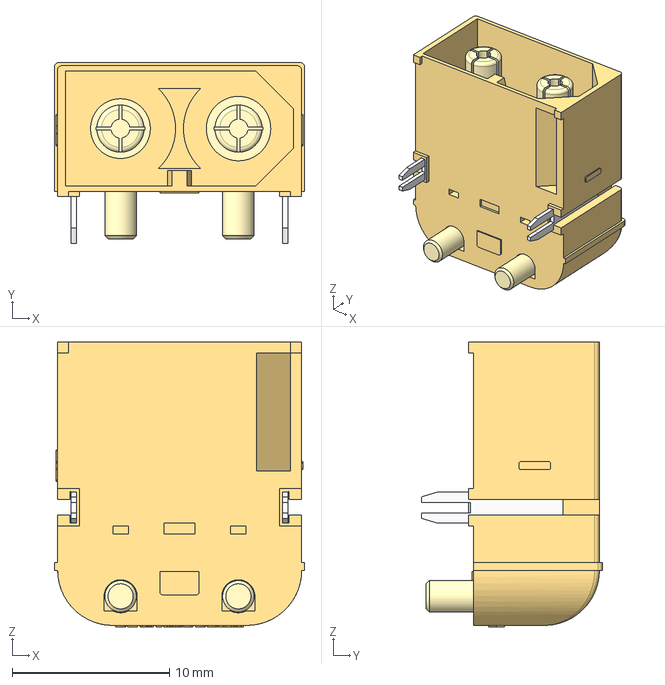
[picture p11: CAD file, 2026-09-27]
hardware/pm100-xiao/3d/XT60PW-M20.stp
15.9 x 11.5 x 18.1 mm

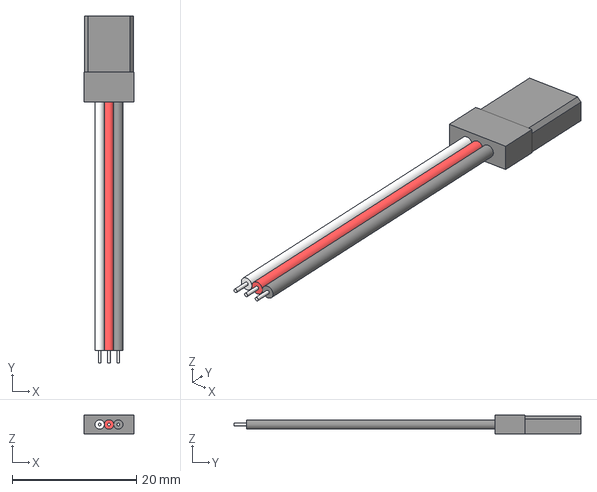
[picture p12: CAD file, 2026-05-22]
hardware/pm100-xiao/3d/cabo_receiver.step
8.00 x 55.8 x 3.00 mm

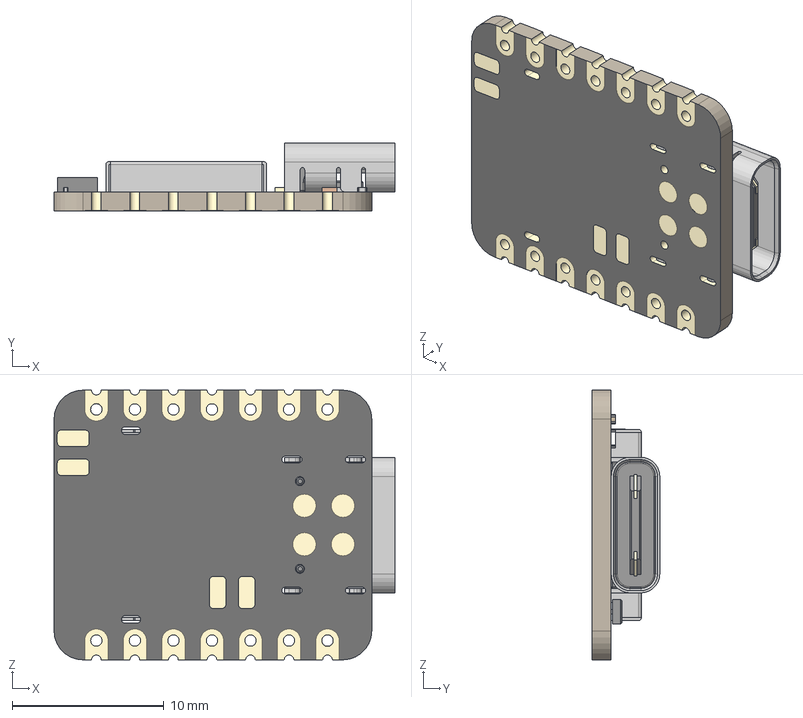
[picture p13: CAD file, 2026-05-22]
hardware/pm100-xiao/3d/XIAO-nRF52840 v15.step
22.5 x 4.46 x 17.8 mm
BOSS-EXTRUDE14_8_
BOSS-EXTRUDE7_4_
BOSS-EXTRUDE7_3_
BOSS-EXTRUDE14_4_
BOSS-EXTRUDE14_2_
BOSS-EXTRUDE14_11_
BOSS-EXTRUDE7_7_
BOSS-EXTRUDE14_9_
BOSS-EXTRUDE14_3_
BOSS-EXTRUDE14_7_
MIRROR2
BOSS-EXTRUDE14_5_
BOSS-EXTRUDE14_12_
BOSS-EXTRUDE7_8_
BOSS-EXTRUDE7_1_
BOSS-EXTRUDE14_10_
BOSS-EXTRUDE7_9_
BOSS-EXTRUDE14_6_
BOSS-EXTRUDE14_1_
BOSS-EXTRUDE7_6_
BOSS-EXTRUDE7_2_
CUT-EXTRUDE5
BOSS-EXTRUDE7_5_
Shield
Pins
CAP x 2
ANT1
Silkscreen
CAP 3
LED
USR
2 v1

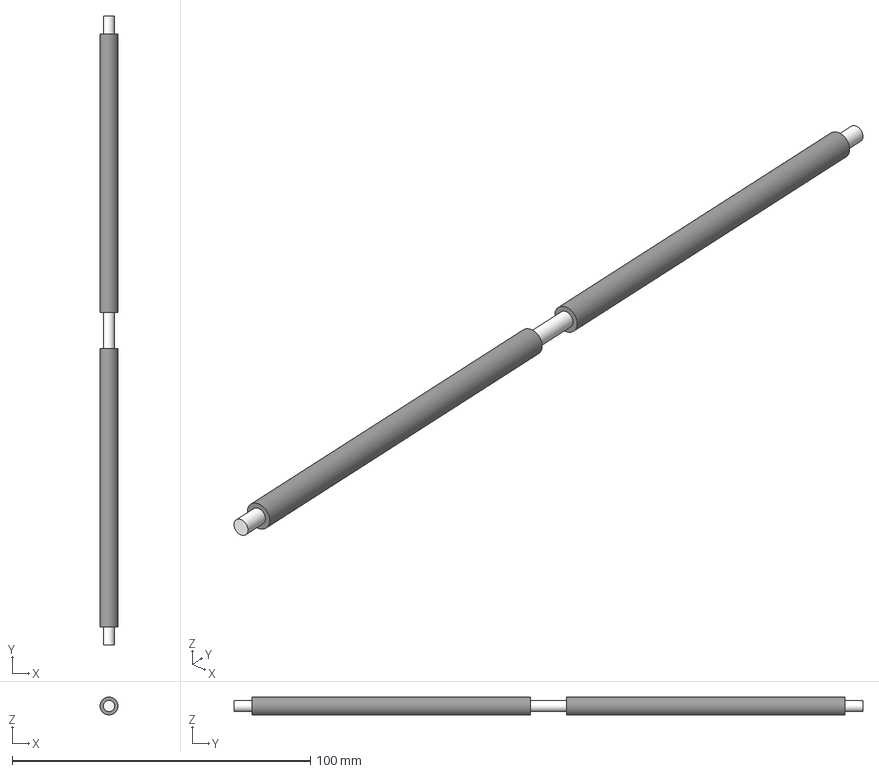
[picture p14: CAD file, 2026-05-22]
hardware/pm100-xiao/3d/cabo_gnd_hv.step
6.00 x 211.0 x 5.99 mm

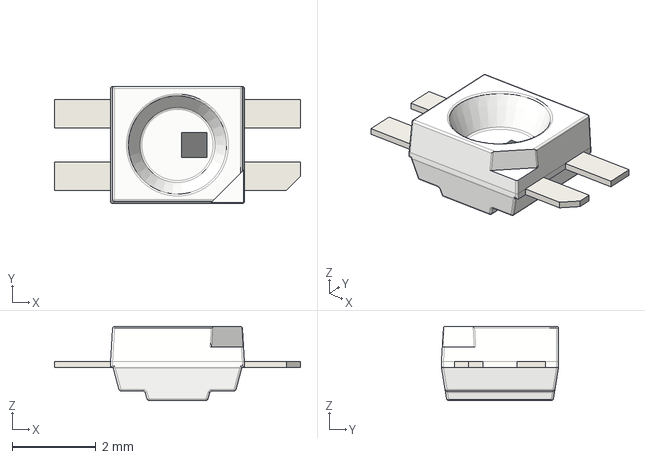
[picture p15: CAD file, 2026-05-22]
hardware/pm100-xiao/3d/LED_SK6812MINI-E.step
5.88 x 2.80 x 1.78 mm

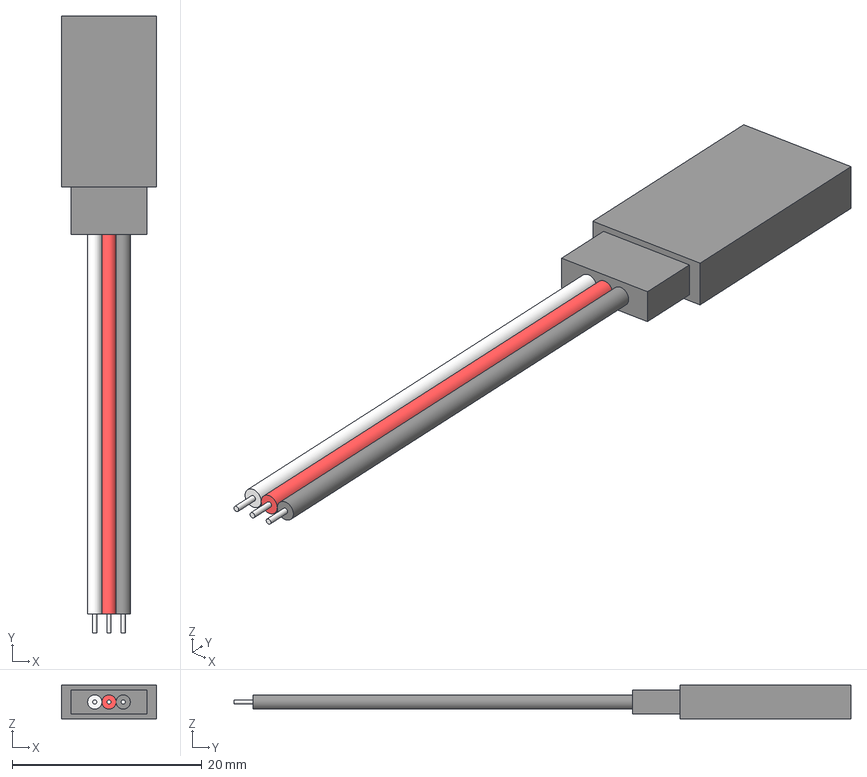
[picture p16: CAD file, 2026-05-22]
hardware/pm100-xiao/3d/cabo_esc.step
10.0 x 65.0 x 3.54 mm

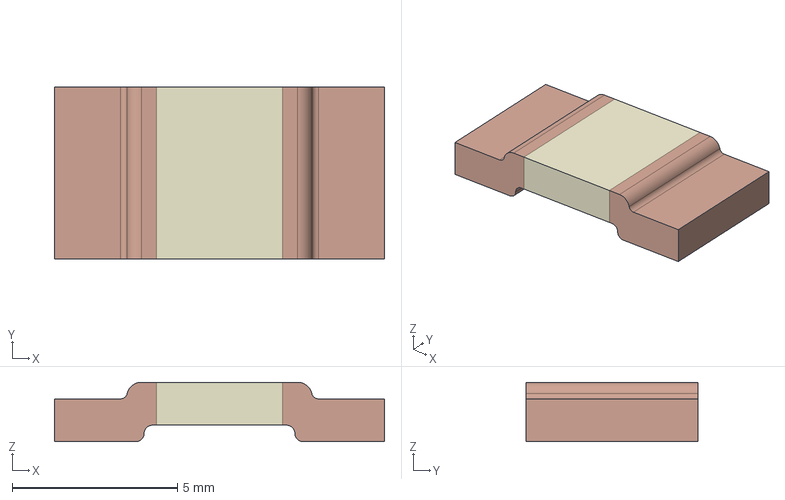
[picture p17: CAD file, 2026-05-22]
hardware/pm100-xiao/3d/MSRSF3920P-1L00-D2P0.stp
10.0 x 5.20 x 1.80 mm

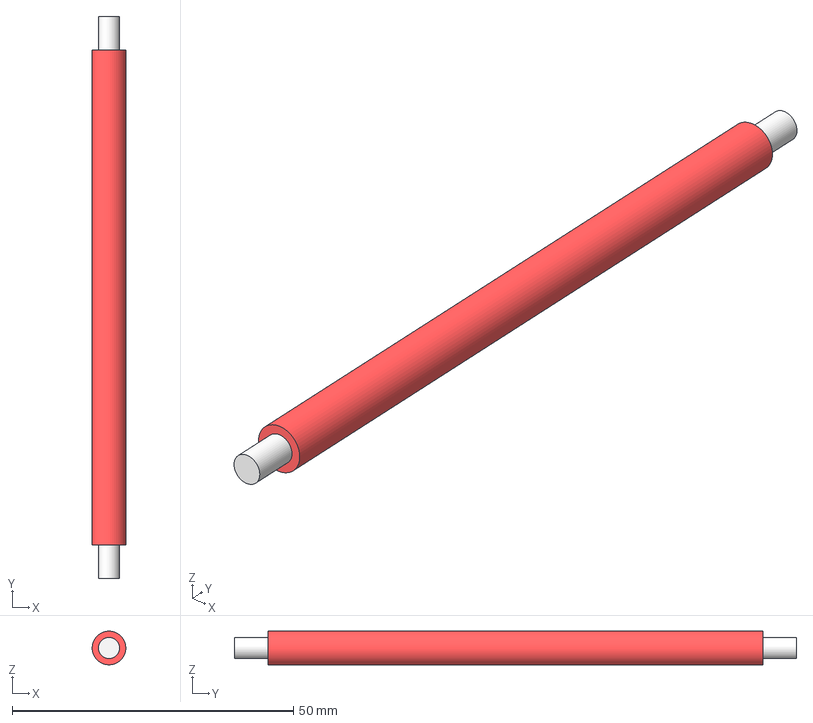
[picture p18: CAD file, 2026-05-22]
hardware/pm100-xiao/3d/cabo_vcc_hv.step
6.00 x 100.0 x 5.99 mm

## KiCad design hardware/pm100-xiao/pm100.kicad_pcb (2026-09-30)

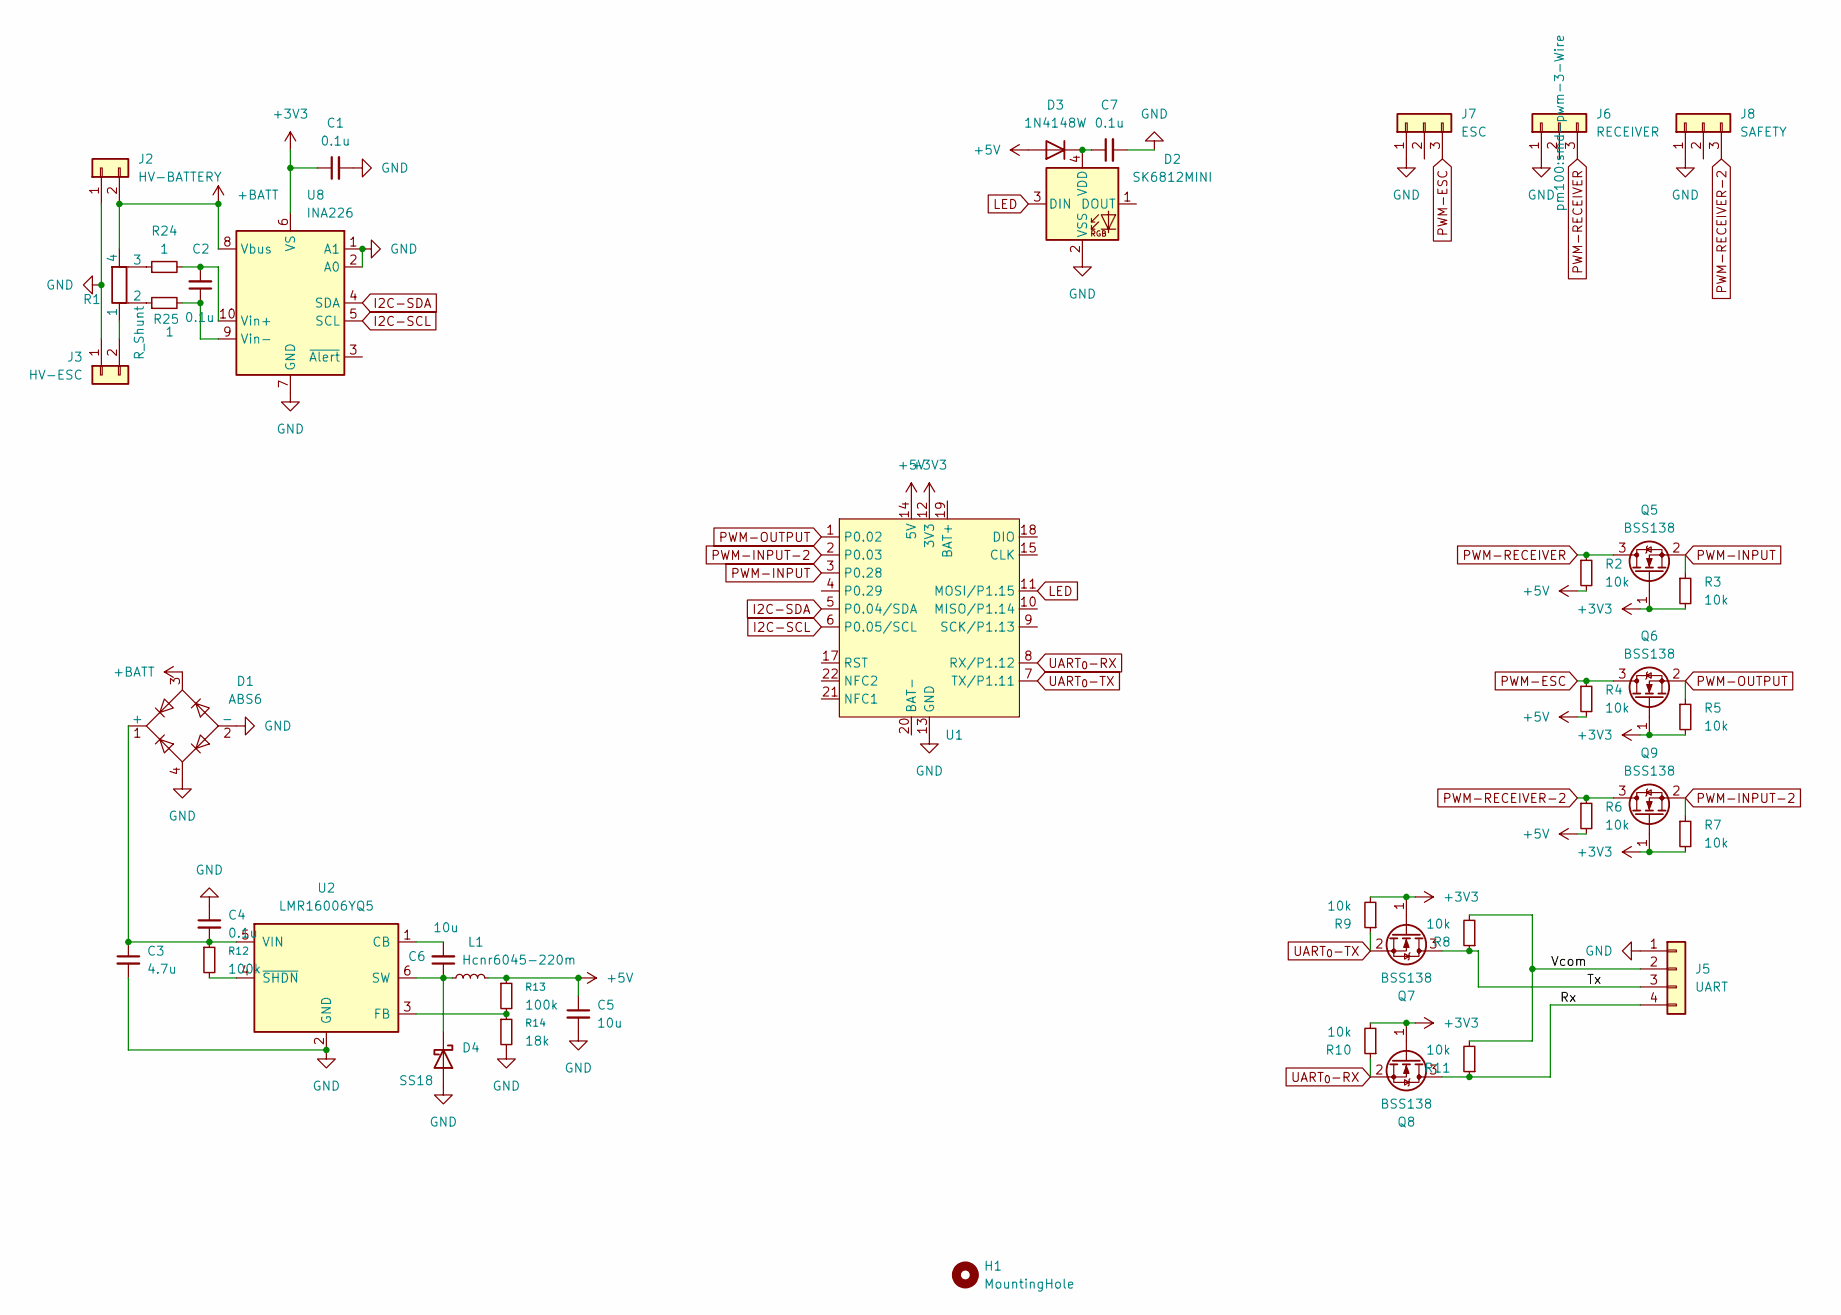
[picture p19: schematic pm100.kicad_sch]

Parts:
C1, C2, C7: 0.1u; C_0603_1608Metric
C3: 4.7u; C_0805_2012Metric
C4: 0.1u; C_0805_2012Metric
C5, C6: 10u; C_0805_2012Metric
D1: ABS6; Diode_Bridge_Diotec_ABS
D2: SK6812MINI; SK6812MINI-E
D3: 1N4148W; D_SOD-123
D4: SS18; D_SMA
H1: MountingHole; MountingHole_3.2mm_M3_ISO7380
J2: HV-BATTERY; AMASS_XT60IPW-M_1x03_P7.20mm_Horizontal
J3: HV-ESC; AMASS_XT60PW-F_1x02_P7.20mm_Horizontal
J5: UART; Hirose_DF13-04P-1.25DS_1x04_P1.25mm_Horizontal
J6: RECEIVER; smd-pwm-3-Wire
J7: ESC; smd-pwm-3-Wire
J8: SAFETY; smd-pwm-3-Wire
L1: Hcnr6045-220m; L_Bourns_SRN6045TA
Q5, Q6, Q7, Q8, Q9: BSS138; SOT-23
R1: R_Shunt; MSRSF3920P
R2, R3, R4, R5, R6, R7, R8, R9, R10, R11: 10k; R_0603_1608Metric
R12, R13: 100k; R_0603_1608Metric
R14: 18k; R_0603_1608Metric
R24, R25: 1; R_0603_1608Metric
U1: Xiao_BLE_sense
U2: LMR16006YQ5; SOT-23-6
U8: INA226; VSSOP-10_3x3mm_P0.5mm

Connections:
+3V3: C1.1, Q5.1 (G), Q6.1 (G), Q7.1 (G), Q8.1 (G), Q9.1 (G), R3.2, R5.2, R7.2, R9.2, R10.2, U1.12 (3V3), U8.6 (VS)
+5V: C5.1, D3.2 (A), L1.2, R2.2, R4.2, R6.2, R13.1, U1.14 (5V)
+BATT: D1.3, J2.2, R1.4, U8.8 (Vbus)
/Rx: J5.4, Q8.3 (D), R11.1
/Tx: J5.3, Q7.3 (D), R8.1
/Vcom: J5.2, R8.2, R11.2
GND: C1.2, C3.2, C4.1, C5.2, C7.2, D1.2 (-), D1.4, D2.2 (VSS), D4.2 (A), J2.1, J3.1, J5.1, J6.1, J7.1, J8.1, R14.2, U1.13 (GND), U1.16 (GND), U2.2 (GND), U8.1 (A1), U8.2 (A0), U8.7 (GND)
I2C-SCL: U1.6 (P0.05/SCL), U8.5 (SCL)
I2C-SDA: U1.5 (P0.04/SDA), U8.4 (SDA)
LED: D2.3 (DIN), U1.11 (MOSI/P1.15)
unnamed: C3.1, C4.2, D1.1 (+), R12.1, U2.5 (VIN)
unnamed: C7.1, D2.4 (VDD), D3.1 (K)
unnamed: C6.1, D4.1 (K), L1.1, U2.6 (SW)
unnamed: J3.2, R1.1
unnamed: R1.2, R25.1
unnamed: R1.3, R24.1
unnamed: C6.2, U2.1 (CB)
unnamed: R13.2, R14.1, U2.3 (FB)
unnamed: R12.2, U2.4 (~SHDN)
unnamed: C2.2, R24.2, U8.10 (Vin+)
unnamed: C2.1, R25.2, U8.9 (Vin-)
PWM-ESC: J7.3, Q6.3 (D), R4.1
PWM-INPUT: Q5.2 (S), R3.1, U1.3 (P0.28)
PWM-INPUT-2: Q9.2 (S), R7.1, U1.2 (P0.03)
PWM-OUTPUT: Q6.2 (S), R5.1, U1.1 (P0.02)
PWM-RECEIVER: J6.3, Q5.3 (D), R2.1
PWM-RECEIVER-2: J8.3, Q9.3 (D), R6.1
UART_{0}-RX: Q8.2 (S), R10.1, U1.8 (RX/P1.12)
UART_{0}-TX: Q7.2 (S), R9.1, U1.7 (TX/P1.11)

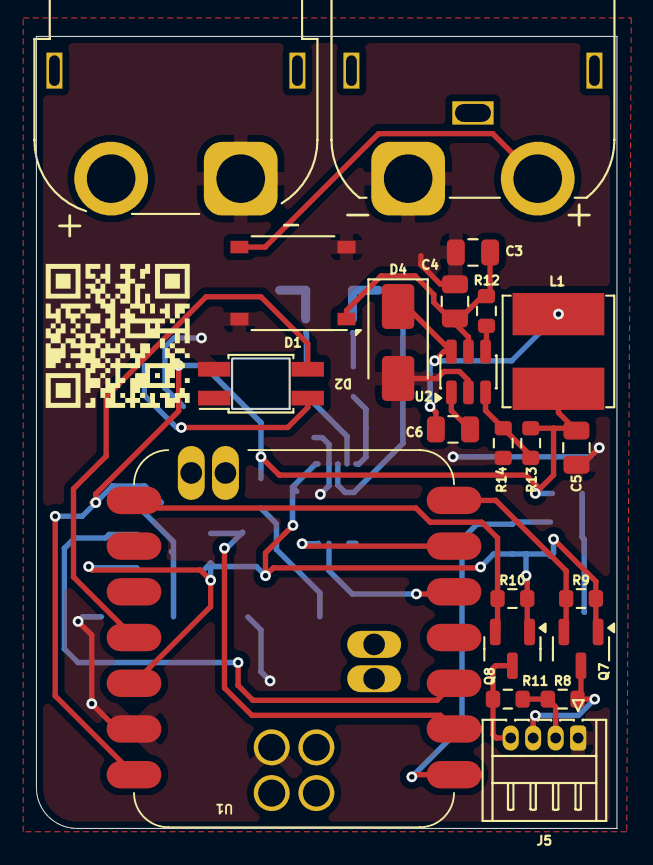
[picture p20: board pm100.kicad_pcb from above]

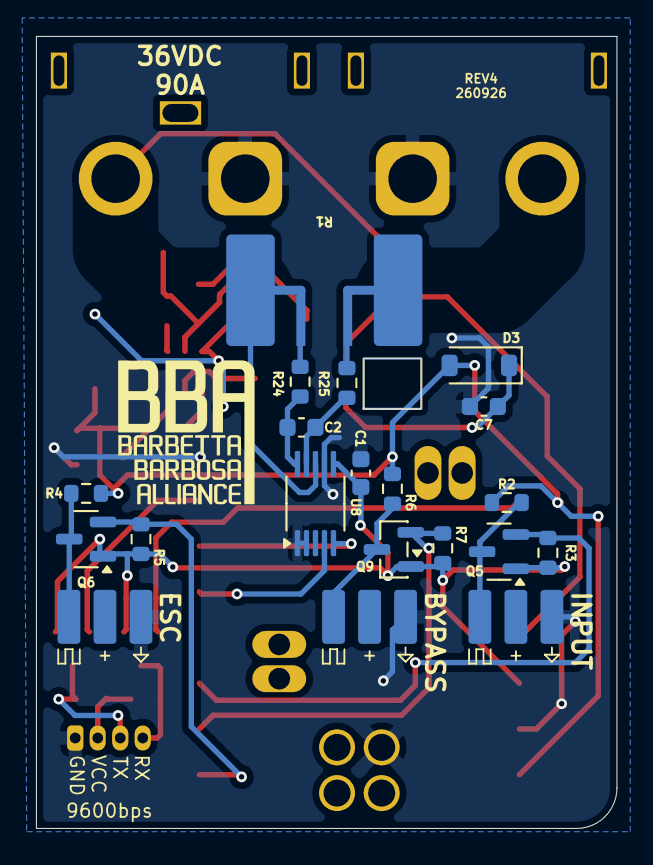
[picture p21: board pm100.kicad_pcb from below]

Board: 2 copper layers, 32.2 x 44.0 mm, 42 parts (20 on the bottom side), 29 nets.

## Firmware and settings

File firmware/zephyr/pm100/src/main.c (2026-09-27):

/*
 * Copyright (c) 2016 Intel Corporation
 *
 * SPDX-License-Identifier: Apache-2.0
 */

#include <stdio.h>
#include <stdlib.h>
#include <string.h>
#include <zephyr/kernel.h>
#include <zephyr/devicetree.h>
#include <zephyr/drivers/gpio.h>
#include <zephyr/logging/log.h>
#include <zephyr/shell/shell.h>
#include <zephyr/device.h>
#include <zephyr/irq.h>
#include <zephyr/drivers/led_strip.h>
#include "control.h"
#include "shell_cmds.h"
#include "ble_telemetry.h"
#include "stream.h"

#define LED0_NODE DT_ALIAS(led0)
#define STRIP_NODE DT_ALIAS(rgba)

LOG_MODULE_REGISTER(PM100_devel, LOG_LEVEL_DBG);

/* Getting peripherals from device tree */
static const struct gpio_dt_spec led = GPIO_DT_SPEC_GET(LED0_NODE, gpios);
static const struct device *const strip = DEVICE_DT_GET(STRIP_NODE);

#define STRIP_NUM_PIXELS DT_PROP(STRIP_NODE, chain_length)

/* Thread definitions */
#define TELEM_THREAD_STACK_SIZE 2048
#define TELEM_THREAD_PRIORITY   K_PRIO_PREEMPT(8)

#define LED_THREAD_STACK_SIZE   1024
#define LED_THREAD_PRIORITY     K_PRIO_PREEMPT(9)

/*
 * Timestamp of the last CLI/BLE white-blink trigger (BLINK_HOLD_MS in control.h
 * sets how long it overrides the state colour). Initialised to a time in the
 * past (not 0) so that the "k_uptime_get() - g_blink_start_time < BLINK_HOLD_MS"
 * test is FALSE at boot: with 0, the first five seconds of every power-up
 * counted as BLINK and the LED was white before it settled into its real state
 * colour.
 */
volatile int64_t g_blink_start_time = -100000;

/*
 * Status LED colour palette (projeto.md, section 1 "Thread 3" state table).
 * Full-scale RGB values; the ws2812-spi driver maps the logical channels to the
 * strip's wire order using "color-mapping" in the devicetree (GREEN, RED, BLUE).
 */
#define LED_COLOR_OFF    ((struct led_rgb){ .r = 0x00, .g = 0x00, .b = 0x00 }) /* black                     */
#define LED_COLOR_GREEN  ((struct led_rgb){ .r = 0x00, .g = 0xFF, .b = 0x00 }) /* #00FF00 -> READY          */
#define LED_COLOR_BLUE   ((struct led_rgb){ .r = 0x00, .g = 0x00, .b = 0xFF }) /* #0000FF -> LIMITING_POWER */
#define LED_COLOR_RED    ((struct led_rgb){ .r = 0xFF, .g = 0x00, .b = 0x00 }) /* #FF0000 -> ERROR_*        */
#define LED_COLOR_WHITE  ((struct led_rgb){ .r = 0xFF, .g = 0xFF, .b = 0xFF }) /* #FFFFFF -> BLINK          */
#define LED_COLOR_ORANGE ((struct led_rgb){ .r = 0xFF, .g = 0x7F, .b = 0x00 }) /* #FF7F00 -> LEARNING       */
#define LED_COLOR_PURPLE ((struct led_rgb){ .r = 0x80, .g = 0x00, .b = 0x80 }) /* #800080 -> BYPASS         */

/**
 * @brief Thread 2 entry point: Updates and transmits telemetry diagnostics at 10Hz.
 * 
 * Drives the CSV formatting of active states and outputs to the console port
 * if stream is enabled.
 */
void telem_thread_handler(void *p1, void *p2, void *p3)
{
    // Wait for serial interface & initialization to settle
    k_msleep(2500);

    LOG_INF("Telemetry Thread (Thread 2) started at 10Hz");

    while (1) {
        k_msleep(100); // 10Hz period

        struct system_telemetry local_telem;

        // Fetch current telemetry thread-safely
        k_mutex_lock(&g_telemetry_mutex, K_FOREVER);
        local_telem = g_telemetry;
        k_mutex_unlock(&g_telemetry_mutex);

        // Print CSV data stream if toggle flag is active
        if (g_stream_active) {
            printf("%llu,%0.2f,%0.2f,%0.2f,%0.2f,%d,%d,%d,%d,%d\r\n",
                   local_telem.time_ms,
                   local_telem.power_w,
                   local_telem.current_a,
                   local_telem.voltage_v,
                   local_telem.total_consumption_j,
                   local_telem.pwm_input_us,
                   local_telem.pwm_bypass_us,
                   local_telem.pwm_output_us,
                   local_telem.pwm_control_us,
                   (int)local_telem.state);
        }

        // Push binary telemetry updates over Bluetooth BLE at 10Hz
        ble_telemetry_update(&local_telem);
    }
}

K_THREAD_DEFINE(telem_thread, TELEM_THREAD_STACK_SIZE, telem_thread_handler, NULL, NULL, NULL, TELEM_THREAD_PRIORITY, 0, 0);

/**
 * @brief Thread 3 entry point: Controls status WS2812 RGB LED signaling at 4Hz.
 * 
 * Reads the controller's current state and updates the blinking pattern dynamically.
 */
void led_thread_handler(void *p1, void *p2, void *p3)
{
    // Wait for hardware systems to initialize
    k_msleep(3000);

    LOG_INF("LED Status Thread (Thread 3) started");

    /* One-shot readiness report: without it a missing/unready strip is silent,
     * and a WS2812B sits at its power-on state (usually solid white), which is
     * indistinguishable from a broken colour implementation. */
    if (device_is_ready(strip)) {
        LOG_INF("WS2812 strip %s ready, %u pixel(s)", DEVICE_DT_NAME(STRIP_NODE),
                (unsigned int)STRIP_NUM_PIXELS);
    } else {
        LOG_ERR("WS2812 strip %s NOT ready: colour output disabled (check the "
                "SPI bus and the worldsemi,ws2812-spi node)",
                DEVICE_DT_NAME(STRIP_NODE));
    }

    bool toggle_state = false;
    while (1) {
        // Retrieve control state computed by the 1 kHz control loop
        k_mutex_lock(&g_telemetry_mutex, K_FOREVER);
        enum ctrl_state state = g_telemetry.state;
        k_mutex_unlock(&g_telemetry_mutex);

        int sleep_ms = 250;
        struct led_rgb color = LED_COLOR_OFF;

        toggle_state = !toggle_state;

        if (state == BLINK) {
            // White, 5Hz (100ms ON, 100ms OFF), triggered via CLI/BLE
            if (toggle_state) {
                color = LED_COLOR_WHITE;
            }
            sleep_ms = 100; // 5Hz blink period per toggle (100ms)
        } else {
            if (toggle_state) {
                switch (state) {
                case READY:
                    color = LED_COLOR_GREEN;
                    sleep_ms = 500; // 1Hz blink (500ms ON)
                    break;
                case LIMITING_POWER:
                    color = LED_COLOR_BLUE;
                    sleep_ms = 125; // 4Hz blink (125ms ON)
                    break;
                case ERROR_NO_INPUT:
                case ERROR_NO_BATTERY:
                    color = LED_COLOR_RED;
                    sleep_ms = 250; // 2Hz blink (250ms ON)
                    break;
                case LEARNING:
                    color = LED_COLOR_ORANGE;
                    sleep_ms = 125; // 4Hz blink (125ms ON)
                    break;
                case BYPASS:
                    color = LED_COLOR_PURPLE;
                    sleep_ms = 250; // 2Hz blink (250ms ON)
                    break;
                default:
                    break;
                }
            } else {
                switch (state) {
                case READY:
                    sleep_ms = 500; // 1Hz blink (500ms OFF)
                    break;
                case LIMITING_POWER:
                    sleep_ms = 125; // 4Hz blink (125ms OFF)
                    break;
                case ERROR_NO_INPUT:
                case ERROR_NO_BATTERY:
                    sleep_ms = 250; // 2Hz blink (250ms OFF)
                    break;
                case LEARNING:
                    sleep_ms = 125; // 4Hz blink (125ms OFF)
                    break;
                default:
                    break;
                }
            }
        }

        // Output to WS2812 RGB strip (if ready). The return value used to be
        // dropped, so an SPI failure was invisible and the strip simply kept
        // showing its previous (power-on) colour.
        //
        // led_strip_update_rgb() expects an ARRAY of STRIP_NUM_PIXELS pixels.
        // Passing the address of a single struct only worked because
        // chain-length == 1; with a longer chain it read past the end of a
        // stack object. Broadcasting through a static array also keeps it off
        // the 1 KiB LED thread stack.
        if (device_is_ready(strip)) {
            static struct led_rgb strip_pixels[STRIP_NUM_PIXELS];
            int strip_rc;

            for (size_t i = 0; i < STRIP_NUM_PIXELS; i++) {
                strip_pixels[i] = color;
            }

            strip_rc = led_strip_update_rgb(strip, strip_pixels, STRIP_NUM_PIXELS);

            if (strip_rc < 0) {
                LOG_WRN_ONCE("led_strip_update_rgb failed (%d); colour output "
                             "is not reaching the strip", strip_rc);
            }
        }

        // Toggle standard on-board GPIO LED as a heartbeat backup
        if (gpio_is_ready_dt(&led)) {
            gpio_pin_set_dt(&led, toggle_state ? 1 : 0);
        }

        k_msleep(sleep_ms);
    }
}

K_THREAD_DEFINE(led_thread, LED_THREAD_STACK_SIZE, led_thread_handler, NULL, NULL, NULL, LED_THREAD_PRIORITY, 0, 0);


int main(void)
{
    // Allow USB CDC ACM interface time to initialize
    k_msleep(2000);

    LOG_INF("Starting PM100 Initialization...");

    int ret;

    LOG_INF("Calling control_init()...");
    ret = control_init();
    if (ret < 0) {
        LOG_ERR("control_init failed with %d", ret);
    } else {
        LOG_INF("control_init success.");
    }

    LOG_INF("Calling ble_telemetry_init()...");
    ret = ble_telemetry_init();
    if (ret < 0) {
        LOG_ERR("ble_telemetry_init failed with %d", ret);
    } else {
        LOG_INF("ble_telemetry_init success.");
    }

    // Claim the second CDC ACM port used by the binary telemetry stream. A
    // failure only disables the stream; the shell and the rest keep working.
    LOG_INF("Calling stream_init()...");
    ret = stream_init();
    if (ret < 0) {
        LOG_ERR("stream_init failed with %d (binary stream unavailable)", ret);
    } else {
        LOG_INF("stream_init success.");
    }

    LOG_INF("Checking LED Pin...");
    if (gpio_is_ready_dt(&led)) {
        ret = gpio_pin_configure_dt(&led, GPIO_OUTPUT_ACTIVE);
        if (ret < 0) {
            LOG_ERR("Failed to configure LED pin: %d", ret);
        }
    }

    LOG_INF("Initialization Complete. Main thread idle.");

    while (1) {
        k_msleep(5000);
    }

    return 0;
}

// SHELL COMMANDS IMPLEMENTATION

static int cmd_update_adrc_gains(const struct shell *sh, size_t argc, char **argv)
{
    if (argc == 1) {
        k_mutex_lock(&g_config_mutex, K_FOREVER);
        float b0 = g_config.b0;
        float kp = g_config.kp;

        shell_print(sh, "Active ADRC (1st-order plant): dt=%0.4f s, wo=%0.1f rad/s, b0=%0.4f (W/s)/us, kp=%0.2f 1/s",
                    (double)g_config.dt, (double)g_config.wo, (double)b0, (double)kp);
        if (g_learning_mode) {
            shell_print(sh, "!! b0 = 0: learning pass-through is ACTIVE, the power limiter is OFF.");
        }
        if (b0 > 0.0f && kp > 0.0f) {
            /* kp = 1/lambda and b0 = K/tau. With the default lambda = tau the
             * plant follows from the gains alone; with an explicit lambda only
             * the authority below is exact. */
            shell_print(sh, "  lambda = 1/kp = %.1f ms; if lambda == tau, then tau = %.1f ms, K = %.4f W/us",
                        (double)(1000.0f / kp), (double)(1000.0f / kp), (double)(b0 / kp));
            shell_print(sh, "  full 1000 us stroke at %.0f W of power error",
                        (double)(1000.0f * b0 / kp));
        }
        shell_print(sh, "  kd=%0.2f is stored but UNUSED by the first-order law.",
                    (double)g_config.kd);
        k_mutex_unlock(&g_config_mutex);
        return 0;
    } else if (argc == 5) {
        float wo = strtof(argv[1], NULL);
        float b0 = strtof(argv[2], NULL);
        float kp = strtof(argv[3], NULL);
        float kd = strtof(argv[4], NULL);

        int ret = control_update_gains(wo, b0, kp, kd);
        if (ret < 0) {
            shell_error(sh, "Failed to update ADRC gains: %d", ret);
            return ret;
        }

        if (b0 == 0.0f) {
            shell_print(sh, "b0 = 0: learning mode enabled. Hold throttle at 10-50%%, then slam to >75%% and hold.");
        } else if (kd != 0.0f) {
            shell_print(sh, "ADRC gains stored in NVS (note: kd=%0.2f is ignored, the law is first-order).",
                        (double)kd);
        } else {
            shell_print(sh, "ADRC gains successfully updated and stored in NVS.");
        }
        return 0;
    } else {
        shell_error(sh, "Invalid arguments. Usage: 'pm100 gains' or 'pm100 gains <wo> <b0> <kp> <kd>'");
        shell_error(sh, "  wo ~ 3-5x kp, b0 = static_gain/tau, kp = 2/tau, kd is ignored.");
        return -EINVAL;
    }
}

static int cmd_target(const struct shell *sh, size_t argc, char **argv)
{
    const struct control_ident_result *res = control_ident_result();
    float lo = 0.0f, hi = 0.0f;

    if (res->valid && res->levels >= 2u) {
        lo = res->p_settled[0];
        hi = res->p_settled[res->levels - 1];
    }

    if (argc == 1) {
        k_mutex_lock(&g_config_mutex, K_FOREVER);
        float tgt = g_config.target_power;
        k_mutex_unlock(&g_config_mutex);

        shell_print(sh, "Active Power Target: %0.2f W", (double)tgt);

        /* The target is useless if the plant cannot reach it, and that failure
         * is invisible in flight: pwm_out == pwm_in and everything looks fine. */
        if (!res->valid) {
            shell_print(sh, "  no identification yet: 'pm100 ident run' learns what this "
                            "plant can actually reach");
        } else {
            shell_print(sh, "  identified range: %0.1f..%0.1f W", (double)lo, (double)hi);
            if (tgt > hi) {
                shell_print(sh, "  ! above the identified range: the limiter can NEVER engage.");
            } else if (tgt < lo) {
                shell_print(sh, "  ! below the identified range: the feedforward is off, "
                                "feedback only.");
            }
        }
        return 0;
    } else if (argc == 2) {
        char *end;
        float target_power = strtof(argv[1], &end);

        if (end == argv[1]) {
            shell_error(sh, "'%s' is not a number.", argv[1]);
            return -EINVAL;
        }

        int ret = control_update_target(target_power);
        if (ret < 0) {
            shell_error(sh, "Failed to update target power: %d. Must be 0 < target <= %d W.",
                        ret, (int)CONTROL_TARGET_MAX_W);
            return ret;
        }

        shell_print(sh, "Target power set to %0.2f W and stored in NVS.", (double)target_power);

        if (res->valid && res->levels >= 2u && target_power > hi) {
            shell_print(sh, "  ! warning: above the identified maximum of %0.1f W, so the "
                            "limiter will never engage.", (double)hi);
        }
        return 0;
    } else {
        shell_error(sh, "Invalid arguments. Usage: 'pm100 target' or 'pm100 target <power_watts>'");
        return -EINVAL;
    }
}

static int cmd_shunt(const struct shell *sh, size_t argc, char **argv)
{
    if (argc == 1) {
        k_mutex_lock(&g_config_mutex, K_FOREVER);
        shell_print(sh, "Active Shunt Resistor: %0.2f mOhm", g_config.shunt_resistor_mohm);
        k_mutex_unlock(&g_config_mutex);
        return 0;
    } else if (argc == 2) {
        float shunt_mohm = strtof(argv[1], NULL);

        int ret = control_update_shunt(shunt_mohm);
        if (ret < 0) {
            shell_error(sh, "Failed to update shunt resistor: %d. Must be > 0.0", ret);
            return ret;
        }

        shell_print(sh, "Shunt resistor successfully updated to %0.2f mOhm and stored in NVS.", shunt_mohm);
        return 0;
    } else {
        shell_error(sh, "Invalid arguments. Usage: 'pm100 shunt' or 'pm100 shunt <value_mohm>'");
        return -EINVAL;
    }
}

static int cmd_team_name(const struct shell *sh, size_t argc, char **argv)
{
    if (argc == 1) {
        k_mutex_lock(&g_config_mutex, K_FOREVER);
        shell_print(sh, "Active Team Name: %s", g_config.team_name);
        k_mutex_unlock(&g_config_mutex);
        return 0;
    } else if (argc == 2) {
        const char *name = argv[1];

        int ret = shell_update_team_name(name);
        if (ret < 0) {
            shell_error(sh, "Failed to set team name: %d", ret);
            return ret;
        }

        shell_print(sh, "Team name successfully updated and stored in NVS.");
        return 0;
    } else {
        shell_error(sh, "Invalid arguments. Usage: 'team_name' or 'team_name <name>'");
        return -EINVAL;
    }
}

static int cmd_team_number(const struct shell *sh, size_t argc, char **argv)
{
    if (argc == 1) {
        k_mutex_lock(&g_config_mutex, K_FOREVER);
        shell_print(sh, "Active Team Number: %u", g_config.team_number);
        k_mutex_unlock(&g_config_mutex);
        return 0;
    } else if (argc == 2) {
        uint32_t number = (uint32_t)strtoul(argv[1], NULL, 10);

        int ret = shell_update_team_number(number);
        if (ret < 0) {
            shell_error(sh, "Failed to set team number: %d", ret);
            return ret;
        }

        shell_print(sh, "Team number successfully updated and stored in NVS.");
        return 0;
    } else {
        shell_error(sh, "Invalid arguments. Usage: 'team_number' or 'team_number <number>'");
        return -EINVAL;
    }
}

static int cmd_set_pin(const struct shell *sh, size_t argc, char **argv)
{
    if (argc == 1) {
        k_mutex_lock(&g_config_mutex, K_FOREVER);
        shell_print(sh, "Active BLE Pairing PIN: %s", g_config.PIN_code);
        k_mutex_unlock(&g_config_mutex);
        return 0;
    } else if (argc == 2) {
        const char *pin = argv[1];

        int ret = shell_update_pin(pin);
        if (ret < 0) {
            shell_error(sh, "Failed to set PIN code: %d. Must be exactly 6 characters.", ret);
            return ret;
        }

        shell_print(sh, "PIN code successfully updated and stored in NVS.");
        return 0;
    } else {
        shell_error(sh, "Invalid arguments. Usage: 'ble_pin' or 'ble_pin <pin_code>'");
        return -EINVAL;
    }
}

static void cmd_stream_status(const struct shell *sh)
{
    struct pm100_stream_stats stats;

    stream_get_stats(&stats);

    if (!stream_is_ready()) {
        shell_print(sh, "Binary stream : UNAVAILABLE (no second CDC ACM port)");
    } else {
        shell_print(sh, "Binary stream : %s, %u ms/frame (%u samples/frame)",
                    stream_is_enabled() ? "ON" : "off",
                    (unsigned int)stream_get_period_ms(),
                    (unsigned int)stream_get_period_ms());
        shell_print(sh, "  frames=%u sent/%u dropped, samples=%u sent/%u dropped, "
                            "%u tx_stalls, %u corrupt",
                    stats.frames_sent, stats.frames_dropped, stats.samples_sent,
                    stats.samples_dropped, stats.tx_stalls, stats.corrupt_records);
    }

    shell_print(sh, "CSV stream    : %s (first CDC ACM port, 10 Hz)",
                g_stream_active ? "ON" : "off");
}

static int cmd_stream(const struct shell *sh, size_t argc, char **argv)
{
    /* Legacy form: `stream <on|off>` toggles the CSV stream on the console
     * port. `stream csv <on|off>` is the explicit spelling of the same thing.
     * `stream bin <on|off> [period_ms]` drives the binary stream on the second
     * CDC ACM port, where period_ms is the frame period (1 kHz control loop, so
     * one period unit == one sample per frame; 1..48).
     */
    const char *what = argv[1];
    const char *state = NULL;

    if (strcmp(what, "status") == 0) {
        cmd_stream_status(sh);
        return 0;
    }

    if (strcmp(what, "bin") == 0) {
        if (argc < 3) {
            shell_error(sh, "Usage: stream bin <on|off> [period_ms]");
            return -EINVAL;
        }
        state = argv[2];
    } else if (strcmp(what, "csv") == 0) {
        if (argc < 3) {
            shell_error(sh, "Usage: stream csv <on|off>");
            return -EINVAL;
        }
        state = argv[2];
    } else if (strcmp(what, "on") == 0 || strcmp(what, "off") == 0) {
        state = what;
    } else {
        shell_error(sh, "Usage: stream <on|off> | stream csv <on|off> | "
                            "stream bin <on|off> [period_ms] | stream status");
        return -EINVAL;
    }

    bool enable;

    if (strcmp(state, "on") == 0) {
        enable = true;
    } else if (strcmp(state, "off") == 0) {
        enable = false;
    } else {
        shell_error(sh, "Invalid state '%s', use 'on' or 'off'.", state);
        return -EINVAL;
    }

    if (strcmp(what, "bin") == 0) {
        if (!stream_is_ready()) {
            shell_error(sh, "Binary stream port not available.");
            return -ENODEV;
        }

        if (argc >= 4) {
            unsigned long period = strtoul(argv[3], NULL, 10);

            if (period == 0 || period > 48) {
                shell_error(sh, "period_ms must be 1..48.");
                return -EINVAL;
            }
            stream_set_period_ms((uint16_t)period);
        }

        stream_set_enabled(enable);
        shell_print(sh, "Binary stream %s (%u ms/frame).",
                    enable ? "enabled" : "disabled", (unsigned int)stream_get_period_ms());
    } else {
        g_stream_active = enable;
        shell_print(sh, "CSV stream %s.", enable ? "enabled" : "disabled");
    }

    return 0;
}

static int cmd_readings(const struct shell *sh, size_t argc, char **argv)
{
    k_mutex_lock(&g_telemetry_mutex, K_FOREVER);
    shell_print(sh, "%llu,%0.2f,%0.2f,%0.2f,%0.2f,%d,%d,%d,%d,%d",
                g_telemetry.time_ms,
                g_telemetry.power_w,
                g_telemetry.current_a,
                g_telemetry.voltage_v,
                g_telemetry.total_consumption_j,
                g_telemetry.pwm_input_us,
                g_telemetry.pwm_bypass_us,
                g_telemetry.pwm_output_us,
                g_telemetry.pwm_control_us,
                (int)g_telemetry.state);
    k_mutex_unlock(&g_telemetry_mutex);
    return 0;
}
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

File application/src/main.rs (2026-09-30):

use dioxus::prelude::*;
use std::collections::VecDeque;
use std::sync::Arc;
use std::time::{SystemTime, UNIX_EPOCH};

mod components;
mod connection;

use components::{ConfigForms, ControlPlot, LevelBars, LiveMetrics, StreamPlot};
use connection::usb::UsbConnection;
use connection::{CsvRecorder, DeviceConnection, DeviceStatus, RecordingState, TelemetryData};

// Hand-crafted high-performance offline monochrome CSS stylesheet (Dual-Theme)
const BASE_STYLE_CSS: &str = include_str!("../assets/style.css");

#[derive(Clone, Debug, PartialEq)]
enum ConnStatus {
    Disconnected,
    Connecting,
    Connected,
}

#[derive(Clone, Copy, PartialEq, Eq)]
enum LeftTab {
    Plot,
    Control,
    Config,
}

fn main() {
    dioxus::LaunchBuilder::new()
        .with_cfg(desktop! {
            dioxus::desktop::Config::new().with_menu(None).with_window(
                dioxus::desktop::WindowBuilder::new()
                    .with_title("Configurador PM100")
            )
        })
        .launch(app);
}

fn app() -> Element {
    let mut connection_status = use_signal(|| ConnStatus::Disconnected);
    let mut telemetry_data = use_signal(|| TelemetryData::default());
    let mut telemetry_history = use_signal(|| Vec::<TelemetryData>::new());

    // Store session peak power (red metric readout)
    let mut max_power = use_signal(|| 0.0f32);

    let mut target_power = use_signal(|| 150.0f32);
    let mut team_number = use_signal(|| 404u32);
    let mut team_name = use_signal(|| "Mock Falcon".to_string());
    let mut pin_code = use_signal(|| "123456".to_string());

    let mut adrc_wo = use_signal(|| 100.0f32);
    let mut adrc_b0 = use_signal(|| 1.0f32);
    let mut adrc_kp = use_signal(|| 1.0f32);

    // Active UI Theme selection (Default: Dark theme)
    let mut is_dark_theme = use_signal(|| true);

    // Active left-column tab (Plot vs. the 3 configuration boxes)
    let mut left_tab = use_signal(|| LeftTab::Plot);

    let device_conn = use_signal(|| {
        let conn: Arc<dyn DeviceConnection> = Arc::new(UsbConnection::auto());
        conn
    });

    // Shared CSV recorder (buffered) + UI-mirroring state/path signals.
    // The recorder must be created once and kept stable across re-renders,
    // otherwise a new (disconnected) recorder is created each render and the
    // binary reader would write to a different one than the start/stop buttons.
    let recorder = use_signal(|| CsvRecorder::new()).cloned();
    let telemetry_recorder = recorder.clone();
    let mut recording_state = use_signal(|| RecordingState::Stopped);
    let mut record_path = use_signal(|| String::new());

    // Most recent shell/log message captured from the device console.
    let mut log_line = use_signal(|| String::new());

    // Reactive telemetry subscription. `use_resource` runs this in the current
    // component scope and re-runs it whenever `connection_status` changes. The
    // inner loop re-subscribes automatically if the stream ends while the device
    // is still connected (e.g. after Android freezes/resumes the process), which
    // previously froze the readouts after the app was backgrounded and reopened.
    let _telemetry_task = use_resource(move || {
        let recorder = telemetry_recorder.clone();
        async move {
            if *connection_status.read() == ConnStatus::Connected {
                let conn = device_conn.cloned();

                loop {
                    if !conn.is_connected().await {
                        break;
                    }

                    match conn.subscribe_telemetry(recorder.clone()).await {
                        Ok(mut rx) => {
                            let mut local_history = VecDeque::new();
                            while let Some(data) = rx.recv().await {
                                telemetry_data.set(data.clone());

                                // Session peak tracker using peek() to avoid subscription loop
                                if data.power_w > *max_power.peek() {
                                    max_power.set(data.power_w);
                                }

                                // 1500 points (30 seconds window at 50 Hz)
                                local_history.push_back(data);
                                if local_history.len() > 1500 {
                                    local_history.pop_front();
                                }

                                telemetry_history.set(local_history.iter().cloned().collect());
                            }
                        }
                        Err(e) => {
                            eprintln!("subscribe_telemetry: {}", e);
                        }
                    }

                    // Stream ended while still connected; retry shortly.
                    tokio::time::sleep(tokio::time::Duration::from_secs(1)).await;
                }
            }
        }
    });

    // Reactive shell/log subscription: collects console messages from the
    // device while connected, keeping only the most recent lines.
    let _log_task = use_resource(move || async move {
        if *connection_status.read() == ConnStatus::Connected {
            let conn = device_conn.cloned();
            match conn.subscribe_logs().await {
                Ok(mut rx) => {
                    while let Some(line) = rx.recv().await {
                        log_line.set(line);
                    }
                }
                Err(e) => eprintln!("subscribe_logs: {}", e),
            }
        }
    });

    // Reads the device configuration and populates the form signals. Returns
    // the future so callers can either await it (during connect) or spawn it
    // (the "Ler Configuração" button).
    let read_config_action = move |_| {
        let conn = device_conn.cloned();
        async move {
            match conn.read_config().await {
                Ok(config) => {
                    target_power.set(config.target_power);
                    team_name.set(config.team_name);
                    team_number.set(config.team_number);
                    pin_code.set(config.pin_code);
                    adrc_wo.set(config.wo);
                    adrc_b0.set(config.b0);
                    adrc_kp.set(config.kp);
                }
                Err(e) => {
                    eprintln!("Failed to read device config: {}", e);
                }
            }
        }
    };

    let connect_action = move |_| {
        spawn(async move {
            connection_status.set(ConnStatus::Connecting);
            tokio::time::sleep(tokio::time::Duration::from_millis(500)).await;
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

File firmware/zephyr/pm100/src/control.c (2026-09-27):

#include "control.h"
#include "persistence.h"
#include "stream.h"

#include <errno.h>
#include <math.h>
#include <stdio.h>
#include <string.h>
#include <zephyr/kernel.h>
#include <zephyr/device.h>
#include <zephyr/devicetree.h>
#include <zephyr/drivers/gpio.h>
#include <zephyr/drivers/pwm.h>
#include <zephyr/drivers/sensor.h>
#include <zephyr/logging/log.h>

#include <nrfx_timer.h>
#include <nrfx_gpiote.h>
#include <nrfx_ppi.h>
#include <hal/nrf_gpio.h>

LOG_MODULE_DECLARE(PM100_devel, LOG_LEVEL_DBG);

#define CONTROL_STACK_SIZE 2048
#define CONTROL_PRIORITY   K_PRIO_COOP(1) // High-priority cooperative thread for precise 1 kHz execution

/* ------------------------------------------------------------------------- */
/* Timebase                                                                  */
/* ------------------------------------------------------------------------- */

/**
 * @brief Monotonic microsecond timebase.
 *
 * The system timer on nRF runs at 32768 Hz, so a microsecond conversion from
 * uptime ticks resolves the control period (~2.7 ms as built) to better than
 * 0.1 %. k_uptime_get() only has millisecond resolution, which is too coarse
 * both for dt in the LESO and for fitting a 30 ms time constant.
 */
static uint64_t ctrl_now_us(void)
{
	return k_ticks_to_us_near64((uint64_t)k_uptime_ticks());
}

/* Measured control period. Published in the stream snapshot so a capture is
 * self-describing; it is NOT the nominal CONTROL_PERIOD_S. */
static float g_loop_dt_s = CONTROL_PERIOD_S;

/* ------------------------------------------------------------------------- */
/* Global shared state                                                       */
/* ------------------------------------------------------------------------- */

struct system_telemetry g_telemetry = {
    .power_w = 0.0f,
    .current_a = 0.0f,
    .voltage_v = 0.0f,
    .total_consumption_j = 0.0f,
    .time_ms = 0,
    .pwm_input_us = PWM_SAFE_STOP_US,
    .pwm_bypass_us = 0,
    .pwm_output_us = PWM_SAFE_STOP_US,
    .pwm_control_us = PWM_SAFE_STOP_US,
    .state = READY
};
K_MUTEX_DEFINE(g_telemetry_mutex);

struct device_config g_config = {
    .dt = 0.001f,               // 1 kHz sampling period
    .wo = 100.0f,               // LESO bandwidth (rad/s); wo*dt = 0.1; overwritten by b0 learning
    .b0 = 0.0f,                 // 0 = enter b0/ADRC learning mode on first boot
    .kp = 60.0f,                // Loop gain [1/s]; overwritten by b0 learning
    .kd = 0.0f,                 // UNUSED by the first-order law (kept in the NVS layout)
    .target_power = 600.0f,     // Power target limit in Watts
    .shunt_resistor_mohm = 1.0f, // Default 1 mOhm shunt
    .team_name = "time",
    .team_number = 0,
    .PIN_code = "123456"
};
K_MUTEX_DEFINE(g_config_mutex);

volatile bool g_stream_active = false;
volatile bool g_learning_mode = false;
volatile enum learning_stage g_learning_stage = LEARNING_STAGE_IDLE;

static volatile bool g_initialized = false;

/* ------------------------------------------------------------------------- */
/* Binary telemetry stream flags                                             */
/* ------------------------------------------------------------------------- */
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

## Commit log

2025-04-02 reiniciando projeto
    [Suporte_tela_OLED.FCStd, bom.csv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]
2025-04-02 adicionado projeto do stm32cubemx com pinagem e periféricos declarados
2025-04-03 adicionado GND no cristal de 8mhz
    [pm100-B_Cu.gbr, pm100-B_Mask.gbr, pm100-Edge_Cuts.gbr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]
2026-03-16 usando Xiao Ble
    [Suporte_tela_OLED.FCStd, bom.csv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]
2026-05-22 troca de arquitetura de stm para nrf52 e uso de Zephyr para o firmware
    [Suporte_tela_OLED.FCStd, bom.csv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]
2026-05-22 removendo submodule projeto pm100
    [pwm-servo.yaml]
2026-05-22 atualizando readme e adicionando arquivos 3ds do hardware
    [LED_SK6812MINI-E.step, MSRSF3920P-1L00-D2P0.stp, XIAO-nRF52840 v15.step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]
2026-05-22 ajustando pinagem LED RGBA
    [pm100.kicad_pcb, pm100.kicad_sch]
2026-09-17 first release version
    [pm100.kicad_sch]
2026-09-22 Fix merge conflict in control.h: keep 1 kHz control period
    [control.h]
2026-09-25 atualizando fonte e adicionado entrada auxiliar para desligar controle
    [pm100.kicad_pcb, pm100.kicad_sch, pm100_log_1790201381.csv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]
2026-09-27 rev4 projeto eletronico
    [DF13-4P-1.25DS.stp, XT60PW-F.STEP, XT60PW-M20.stp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]
2026-09-30 bug logs não salvos, revisão do hardware pronta para produção
    [pm100.kicad_pcb, pm100_log_1790215208.csv, pm100_log_1790215225.csv]
